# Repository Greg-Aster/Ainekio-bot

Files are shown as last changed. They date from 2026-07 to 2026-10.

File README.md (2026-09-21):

# Ainekio the Robot Familiar

  Ainekio the Robot Familiar is a hardware and software project for building a small robot companion powered by MetaHuman OS. The robot uses a physical body,
  onboard sensors, and a network connection to let MetaHuman OS see, listen, speak, move, and interact through a physical chassis.

- Progress blog and current status: [ainek.io](https://ainek.io)
- MetaHuman OS development repo: [Greg-Aster/metahuman-os](https://github.com/Greg-Aster/metahuman-os)
- Current test body: based on the Sesame robot: [dorianborian/sesame-robot](https://github.com/dorianborian/sesame-robot)

## Robot Models

- **V1 / eight servos:** the existing Freenove ESP32-S3 robot, with direct
  MCPWM servo outputs. [Wiring and hardware records](docs/v1-8servo/PINOUT_DIAGNOSTICS.md).
- **V2 / twelve servos:** native ESP32-P4-WIFI6 bring-up with a PCA9685 driver;
  electrical acceptance and body motion remain pending. [V2 status](docs/v2-12servo/README.md).

Both models are intended to use the same gateway and Body Control interface.
V1 remains supported alongside V2. The complete motion runtime currently implements V1;
[Robot Models](docs/ROBOT_MODELS.md) records the separation boundaries and the
remaining code work for V2.

## Repository Layout

- `Master/` - remote brain and gateway code.
- `Slave/hardware/v1-8servo/` - V1 CAD and physical-body assets.
- `Slave/hardware/v2-12servo/` - V2 CAD, source assemblies, and printable parts.
- `Slave/software/` - portable slave-brain core, protocol, and tests.
- `Slave/firmware/esp32s3/` - current V1 firmware that runs on the robot.
- `Slave/firmware/esp32p4-wifi6/` - native V2 board/network/output-disable bring-up.
- `Emulator/` - host body emulator, Sesame visual simulator, and tests.
- `docs/` - specifications, progress records, repository map, and the ignored
  Sesame reference clone.

The V1 physical robot entry point is
`Slave/firmware/esp32s3/main/app_main.c`. See `docs/REPOSITORY_MAP.md` for the
complete ownership map.

Run the complete local software stack with:

```sh
cp .env.example .env
# Set AINEKIO_ENVIRONMENT_ADAPTER_TOKEN to the adapter token used by MetaHuman OS.
./start.sh
```

This one command starts the visual simulator, protocol-v1 body emulator, Master
gateway, operator dashboard, and authenticated environment adapter. The
launcher refuses to start when the shared bridge token is missing instead of
silently running a disconnected gateway. It prints the dashboard password and
local inspection URLs; pressing `Ctrl+C` stops the entire stack. Run all A1-A30
software acceptance gates with
`python3 Emulator/tools/run_acceptance.py`.

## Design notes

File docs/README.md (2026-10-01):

# Ainekio Documentation Authority

## Normative set

The normative system set is:

- `Ainekio - System Specification v1.0.docx` - behavior, protocol, software,
  safety, and acceptance authority.
- [Parts Overview](https://docs.google.com/document/d/1wz0kyqttPK3HHL0P0_9lLtRW_B87U5u4kEt-UhttHFA/edit?usp=sharing)
  - externally maintained electrical-parts authority named by the specification.

System Specification v1.0 supersedes the archived v0.6 specification and its
Amendment 1 freeze. The Parts Overview supplies planned electrical facts, but
delivered markings, wiring, measurements, photographs, and H-series results are
required before those values count as installed-hardware evidence.

## Maintained implementation documents

Model-specific hardware records live under `v1-8servo/` and `v2-12servo/`.
Shared system, protocol, and bridge documents remain here. The existing
specification's V1 electrical assumptions do not define the V2 board or wiring;
[Robot Models](ROBOT_MODELS.md) records the approved separation and current
implementation boundary.

| Document | Current purpose |
| --- | --- |
| [ROBOT_MODELS.md](ROBOT_MODELS.md) | V1/V2 model, board, servo-output, and shared-code boundaries |
| [V1 hardware bring-up](v1-8servo/HARDWARE_BRINGUP_CHECKLIST.md) | V1 power topology, staged assembly procedure, open physical gates, and recorded board evidence |
| [V1 pinout diagnostics](v1-8servo/PINOUT_DIAGNOSTICS.md) | V1 Freenove header numbering, the flashed GPIO map, peripheral wiring, and expected diagnostic values |
| [V2 hardware record](v2-12servo/README.md) | Selected ESP32-P4-WIFI6/PCA9685 hardware, design assets, and current implementation limits |
| [V2 firmware design](v2-12servo/FIRMWARE_DESIGN.md) | V1 review, P4/PCA9685 requirements, controller/Q6A boundaries and staged acceptance |
| [Body Control Integration](BODY_CONTROL_INTEGRATION.md) | Selected wireless/offboard Q6A direction, USB comparison, ROS 2 role, operating targets and audit findings |
| [Distributed robot foundation](DISTRIBUTED_ROBOT_FOUNDATION.md) | Universal P4 control, Q6A/remote/manual takeover, shared status/routing/queues, ROS comparison and migration gates before feature coding |
| [Complete robot resource budget](v2-12servo/RESOURCE_BUDGET.md) | Power branches, P4/Q6A memory and processing, all equipment, camera/audio quality, motion timing, pins and wired/Wi-Fi comparisons; reproducible arithmetic and final qualification boundaries |
| [Budget audit evidence](v2-12servo/BUDGET_AUDIT_EVIDENCE.md) | Repository/source identities, manufacturer references, Q6A Wi-Fi capability readback, offline Kokoro timing/RSS and exclusions of stale evidence |
| [V2 Step 1 evidence](v2-12servo/STEP1_EVIDENCE.md) | Build/flash commands, tests, actual board/network results and outstanding electrical proof |
| [SLAVE_BRAIN_PROGRESS.md](SLAVE_BRAIN_PROGRESS.md) | Current robot-body software status, implementation evidence, and deliberately pending work |
| [LOCAL_WAKE_WORD.md](LOCAL_WAKE_WORD.md) | Owner-local microWakeWord training, packaging, installation, and validation workflow |
| [freestyle-movement.md](freestyle-movement.md) | Owner-approved bounded motion-plan extension, emulator evidence, and physical enablement gate |
| [REPOSITORY_MAP.md](REPOSITORY_MAP.md) | Current Master, Slave, Emulator, documentation, and reference ownership map |
| [ROS2_SETUP.md](ROS2_SETUP.md) | Desktop ROS tools, validation, and portability requirements for later Q6A deployment |

These documents describe current implementation and evidence. They do not
silently amend the normative specification. A behavioral conflict requires a
numbered specification erratum or revision; installed electrical facts require
recorded H-series evidence.

## Current v1.0 deltas awaiting specification consolidation

System Specification v1.0 predates several implementation discoveries and
owner-approved extensions. Until they are consolidated by numbered erratum or a
new specification revision, readers must keep these boundaries explicit:

- The delivered N16R8 board cannot use the provisional GPIO33/34 servo map in
  specification section 6.3. Hardware testing proved those pins corrupt octal
  PSRAM. The flashed board profile uses GPIO47/48 for R4/R3 and hands GPIO0/43
  from BOOT/UART to the OLED. `v1-8servo/PINOUT_DIAGNOSTICS.md` is the V1 physical
  wiring reference; the old provisional map must not be wired.
- Owner policy as of 2026-08-03 makes the GPIO3 battery sensor telemetry and
  warning-only. The firmware still classifies low, critical, recovered, and
  disconnected readings, but those readings never lock motion, cancel audio,
  close the gateway, or enter deep sleep. Undervoltage shutdown is owned only
  by the battery pack's hardware protection circuit. The installed pack's
  cutoff behavior is not yet documented, so it must be treated as unverified
  and replaced with a properly protected pack if necessary.
- The checked firmware uses a stable per-device eight-character WPA2 setup key
  instead of generating a new 12-character secret for every entry. Joining
  `Ainekio-Setup` is the only setup authentication step; the portal opens its
  configuration form directly at `http://192.168.4.1/` and rejects requests
  outside the setup AP interface. The OLED reports the setup address/key and
  then the joined SSID, DHCP address, and gateway state. This owner-approved UX and
  security change is flashed and broadcasting its setup AP, but still awaits
  physical form-submission evidence and numbered specification consolidation.
- The local wake-word control plane and inference engine are implemented, but no
  accepted production `Ainekio` model is installed. First boot remains
  `wake_enabled=false` and `wake_ready=false`.
- `motion_plan_v1` is an owner-approved bounded extension implemented in the
  protocol/core, gateway, environment adapter, emulator, and current ESP32-S3
  source. The physical port reuses the existing prepared motion buffer/task and
  post-action camera callback. The matching revision is flashed, digest-verified,
  and connected; physical freestyle remains pending owner-supervised transition,
  stop, completion-image, and memory-headroom validation.
- Local robot transport now defaults to `_ainekio._tcp.local` DNS-SD discovery,
  rejects off-subnet advertised addresses, and caches the last authenticated
  local endpoint as a first-attempt optimization. A stale cached endpoint gets
  one bounded attempt before DNS-SD resumes; it is not a fixed configuration.
  Reconnect backoff resets after authenticated `welcome` and never exceeds 15
  seconds. Local mode never silently falls back to the optional Cloudflare
  relay. The owner selected authenticated `ws://` on the private home WPA2 LAN
  as the intentionally minimal local transport; pinned local WSS is not a
  parallel pending path. The maintained implementation uses one-second control
  pings and a four-second active-motion stale guard without timer-driven session
  teardown. Actual Wi-Fi/WebSocket errors still enter FAILSAFE/offline. The v1.0
  DOCX needs a numbered erratum for this
  local-discovery and liveness contract. The keepalive-free application is
  prepared in source but has not yet been flashed; the dated bridge-liveness
  handoff records the exact source-versus-controller boundary.

## Reference inputs

- `Freenove_ESP32_S3_WROOM_Board-main/` contains the vendor board pinout,
  tutorial, driver, and datasheet bundle used to identify physical headers and
  fixed onboard buses. It is reference material, not Ainekio behavior authority.
- `sesame-robot/` is the upstream Sesame source reference used by deterministic
  asset conversion and parity inspection. It is not linked into the runtime and
  does not own Ainekio protocol or safety behavior.

## Archive

`archive/` contains superseded specifications and historical progress material.
Archived files preserve lineage and evidence only; they must not be cited as the
current design. See [archive/README.md](archive/README.md).

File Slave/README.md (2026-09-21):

# Slave

This folder contains the physical robot body and all code that belongs to it.

- `hardware/v1-8servo/` contains the existing eight-servo body's CAD and parts.
- `hardware/v2-12servo/` contains the twelve-servo body's design assets.
- `software/` contains portable robot logic, safety, protocol, and host tests.
- `firmware/esp32s3/` contains the current V1 platform firmware.
- `firmware/esp32p4-wifi6/` contains the native V2 bring-up target and PCA9685 driver.

The ESP32-S3 firmware entry point is
`firmware/esp32s3/main/app_main.c`. The portable control and safety core is
`software/core/` and is compiled into that firmware. Portable WiFi provisioning
state and the versioned NVS contract also live in `software/core/`.

The portable core and protocol currently include V1's eight-joint assumptions.
The approved [model separation](../docs/ROBOT_MODELS.md) keeps reusable control
logic here and assigns each body's joints, poses, and motions to its own model.
V2 command admission and board/network bring-up are implemented. Model extraction,
twelve-joint motion and hardware acceptance remain pending; see the
[Step 1 evidence](../docs/v2-12servo/STEP1_EVIDENCE.md).

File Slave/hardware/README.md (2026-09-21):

# Robot Hardware Assets

| Robot model | Assets | Hardware documentation |
| --- | --- | --- |
| V1 / eight servos | [v1-8servo/](v1-8servo/) contains the existing `3d-print/` and `Parts/` trees | [V1 wiring](../../docs/v1-8servo/PINOUT_DIAGNOSTICS.md) |
| V2 / twelve servos | [v2-12servo/](v2-12servo/) contains V2 source assemblies, Blender files, and printable parts | [V2 hardware record](../../docs/v2-12servo/README.md) |

Source assemblies, Blender work files and backups, and printable exports retain
their original names and contents. A WIP or review filename is not a declaration
of print readiness or physical validation.

Use these model directories for all opens, saves, and exports.

See [Robot Models](../../docs/ROBOT_MODELS.md) for code and board ownership.

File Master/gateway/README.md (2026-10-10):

# Ainekio Gateway

The gateway owns the brain side of each protocol-v1 robot WebSocket. Production
mode authenticates robot sessions, assigns epochs and command sequences, tracks
command lifecycle results, and serves the password-protected local operations
dashboard. Robot tokens, the dashboard password verifier, and the bounded audit
log live under the ignored `build/gateway/` runtime directory by default.

## Physical Robot Gateway

The physical robot and the Environment Bridge share one authenticated,
full-duplex gateway process. Ainekio connects to the LAN-facing `/robot` route;
MetaHuman OS connects from loopback to `/environment`. Non-loopback peers are
rejected from `/environment`, as are requests carrying Cloudflare relay
headers. Once established, either side can send data,
so the fact that the ESP32 initiates its connection does not make communication
one-way.

On first pairing, supply a strong robot token. Configure a separate Environment
Bridge token when using MetaHuman on this host; standalone Body Control does not
require MetaHuman. Do not commit either value:

```sh
export AINEKIO_ROBOT_ID='ainekio-01'
export AINEKIO_ROBOT_TOKEN='<strong generated robot token>'
export AINEKIO_ENVIRONMENT_ADAPTER_TOKEN='<strong generated environment token>'
# Optional first-run password; later launches reuse the saved password.
export AINEKIO_DASHBOARD_PASSWORD='<strong local dashboard password>'
./Master/start-physical-gateway.sh
```

The launcher listens for the robot and Environment Bridge on `0.0.0.0:8790`
but permits `/environment` only from loopback and keeps the dashboard on
`127.0.0.1:8791`. In the default local mode the
launcher advertises `_ainekio._tcp.local` with a host-specific service name. P4
firmware advertising `gateway_switching_v1` tries the saved addresses for its
associated Wi-Fi, then discovered protocol-v1 LAN gateways on that subnet. It
keeps an authenticated connection until that connection fails or the gateway
stops. Discoveries are bounded to eight and stay in RAM for that network
association. A
same-computer MetaHuman OS process continues to use
`ws://127.0.0.1:8790/environment`. Runtime tokens and password verifiers remain
under ignored `build/gateway/physical/` storage.

Older P4 firmware retries one configured URL and requires an update for this
switching behavior. The S3 consumer retains its single-candidate ambiguity result.
The [distributed foundation](../../docs/DISTRIBUTED_ROBOT_FOUNDATION.md) records
the remaining cross-installation work and control-grant design.

This one-off home deployment intentionally uses authenticated `ws://` on the
owner's private WPA2 LAN. It is the smallest local path, but the LAN is part of
the trust boundary: do not use it on guest, shared, or public WiFi. Remote
endpoints remain explicitly configured `wss://` addresses with certificate
verification. TLS-only Wi-Fi profiles never fall back to discovered plain WS;
configure a LAN address on that same network to opt into discovery there.
The dashboard reuses its saved operator password across launches. A first run
without `AINEKIO_DASHBOARD_PASSWORD` generates and prints a password once when
launched in an interactive terminal; an unattended first run requires that
environment variable. Later launches do not generate or print another password.
Use **Settings → Body Control password** to change it with your current password.
The environment variable seeds a missing password store only; it cannot undo a
later password change. Only the verifier persists; plaintext passwords are not
saved by the dashboard. Browser sessions last 30 days and survive server
restarts. Logging out revokes the session. A password change keeps the current
browser signed in and signs out other browsers.
Session token hashes and CSRF state are stored in the owner-only ignored runtime
file `dashboard-sessions.json` alongside `dashboard-auth.json`.
Dashboard authentication is separate from robot WiFi setup and is never
presented by the ESP32 setup portal.

**Settings → Robot Wi-Fi and pairing** reads and edits P4 settings over the
existing authenticated connection when firmware advertises `robot_settings_v1`.
Older firmware shows an update message. The operator can save four connection slots,
each with Wi-Fi credentials and a Body Control URL, remove a connection,
change the robot setup-hotspot password, and change its pairing token. Passwords
are write-only: unchecked password options preserve the saved secret; checking
an option with an empty Wi-Fi password explicitly selects an open network.
WPA2 passphrases follow the radio's 8–63 ASCII requirement (station profiles also
accept a 64-digit hexadecimal PSK); the dashboard login has no such policy.
With `gateway_switching_v1`, two slots may name the same Wi-Fi and different
computer/tunnel addresses. They share one Wi-Fi password; changing it updates
all slots for that network. Adding another address may omit the already saved
password. Duplicate network/address pairs are rejected. Older firmware is
explicitly rejected before a same-network alternate is written.

Read the robot settings before editing. Saves carry the device revision so a
stale browser cannot overwrite another editor's changes. Saving disables output
and persists settings without dropping the running connection. **Restart robot
to apply** is a separate confirmed action; normal startup can move servos to
saved Home positions. A save/restart response confirms that operation, not
successful reconnection. Secrets are omitted from readback, status and audit.

Pairing changes persist the old and new credentials on this server before the
robot receives the write. Both survive a gateway restart or ambiguous device
result. The first authenticated connection using the new token promotes it and
retires the old one. Reuse that pending token when retrying an uncertain save;
apply/reconnect before starting another rotation. Other server installations
must be given the matching token separately. The existing Generate/Revoke
controls still manage server pairing only. Startup environment tokens seed
missing identities and never overwrite a saved token.

## Using more than one computer

The robot identity belongs to the robot. Each host runs the same gateway and uses
the existing robot token and Body Control password. Transfer those credentials
once using the existing security owners; copying `.env` alone is insufficient.
On the working computer, from the repository root:

```sh
./Master/start-physical-gateway.sh --export-pairing /tmp/ainekio-pairing.json
```

Privately transfer that owner-only file to the other computer, then run:

```sh
chmod 600 /tmp/ainekio-pairing.json
./Master/start-physical-gateway.sh --import-pairing /tmp/ainekio-pairing.json
./Master/start-physical-gateway.sh --check
```

Import starts no listeners or services and is idempotent for the same credentials.
It validates both stores before writing; different existing credentials are
preserved with an explicit error. A disk failure can leave one newly imported
store; repeating that same import completes it. The bundle contains tokens and
the password verifier, including any pending token transition. It excludes
browser sessions, tasks, action receipts, logs, Python paths, MetaHuman credentials
and Cloudflare tunnel credentials. Delete the transfer file when finished.
Later password/token changes are local to each installation; copy the matching
credentials to other hosts again rather than assuming automatic synchronization.

Both hosts install their own gateway dependencies and use their own checkout's
`.venv`. Keep machine paths out of shared configuration. Each optional MetaHuman
Bridge retains its matching adapter token. The robot relay hostname remains
`/robot` only. A separate Cloudflare Access TCP hostname can connect a remote
MetaHuman desktop as described below; its credentials/configuration stay local.

- **Same LAN:** a paired gateway with local discovery enabled can be found after
  the current gateway stops. Multiple advertisements are candidates, not an
  error or permission for simultaneous controllers.
- **Different hotspots:** save their SSIDs/passwords and server addresses once.
  P4 cycles distinct networks when Wi-Fi is offline, then selects gateways on
  the associated network. Turn off the previous hotspot when switching SSIDs;
  a still-working Wi-Fi connection is retained. With `AINEKIO_HOTSPOT=1`, the
gateway stops its managed hotspot on shutdown.
- **Cloudflare/remote:** save the `wss://.../robot` endpoint on the relevant Wi-Fi.
  It uses the same pairing and command/result contract with verified TLS.

Start Body Control on the desired host and stop it on the current host using
`./Master/stop-physical-gateway.sh` (or Ctrl+C for a foreground launcher).
A returning host does not seize a healthy connection. The P4 destroys the old
WebSocket and closes admission before opening another. Stop/disconnect output
disable and generation fencing remain; interrupted actions return their existing
disconnect outcome. Connection switching does not transfer a MetaHuman objective,
replay movement or copy a durable execution database.

A phone browser can use an available host's password-protected dashboard when
that host's `AINEKIO_DASHBOARD_HOST` is bound to its private LAN address. The
default dashboard remains loopback. Direct on-P4 browser control is separate
from its setup portal and is not implemented by this change.

The launcher stays in the foreground. Press Ctrl+C to stop it. For normal
owner operation it can instead be supervised by the included user service.
The launcher uses `.venv/bin/python3` from this checkout; `AINEKIO_PYTHON` can
select another absolute interpreter path with the gateway dependencies installed.
Check local prerequisites without opening listeners or printing credentials:

```sh
./Master/start-physical-gateway.sh --check
```

This checks the interpreter, dependencies, discovery executable when enabled, and
saved pairing/password-store validity and recognition/Bridge configuration.
It does not verify network/port
availability or a physical connection.

Install the user service for this checkout without enabling or starting it:

```sh
./Master/start-physical-gateway.sh --install-service
systemctl --user daemon-reload
```

The installer preserves unmanaged existing units. After `.env` contains the
required tokens and the check passes, explicitly enable operation with:

```sh
systemctl --user enable --now ainekio-gateway.service
```

After that, the gateway and its discovery advertisement start when the owner
logs in and restart after a process failure. Rerun the installer and daemon reload
after moving the checkout. The unmodified tracked template assumes `~/Ainekio`.

On a host with the Ainekio hotspot services installed, set `AINEKIO_HOTSPOT=1`
in the ignored `.env` to select hotspot mode at startup. In Body Control,
**Settings → Robot connection mode** switches between the existing Wi-Fi network
and the configured robot hotspot immediately, saving the choice in `.env`.
The running gateway starts `ainekio-hotspot-dhcp.service` and its dependencies,
then stops `ainekio-hotspot-interface.service` and its dependent services when
switched to Wi-Fi or when the gateway exits, including a failed startup.
Switching does not restart Body Control. A robot using the hotspot reconnects
through its saved Wi-Fi profiles when that hotspot is turned off.
The operator needs permission to
start/stop those specific system units without an interactive prompt. Disable
their independent boot enablement when using this gateway-owned lifecycle.
The default is `0`, so other hosts need no hotspot services. Body Control's
dashboard login and robot pairing authentication continue to use their existing
owners. The launcher loads `.env`; a direct `python3 -m gateway.server` invocation
uses `AINEKIO_HOTSPOT` from its process environment and saves UI choices to `.env`
in its working directory.

To install these missing services on Ubuntu, install the packaged dependencies
and run the existing-contract installer once as root:

```sh
sudo apt-get install --no-install-recommends hostapd dnsmasq-base iw iproute2 network-manager polkitd
sudo python3 Master/install-robot-hotspot.py --interface wlan0 --operator "$USER" \
  --credentials /private/path/hostapd.conf
```

Run from the repository root; select the actual station interface and an
owner-only (0600) hostapd file containing the existing `ssid` and either
`wpa_passphrase` or `wpa_psk`. Privately copy that identity from the working
host to reuse the robot's saved Wi-Fi credentials. The installer copies only
those fields; desktop interface names and other hostapd settings are not imported.
It preserves unmanaged existing files with an explicit error and installs
no independently boot-enabled hotspot. Stop the gateway before updating the
installed configuration. Set `AINEKIO_HOTSPOT=1` in `.env` and use the normal
launcher to start it.

The radio must support an AP alongside its station connection; inspect `iw list`
for valid interface combinations. The installer adds `aineap0`, leaves the
station connection intact and defaults to 2.4 GHz channel 1. Use `--channel`
for another permitted channel (1–11); hardware limited to one channel requires
a compatible uplink channel or another adapter. Verify actual radio operation.
The separate interface serves the private `10.42.77.0/24` robot LAN, with the
gateway at `ws://10.42.77.1:8790/robot`. DHCP is confined to that interface and
does not advertise Internet routing or DNS. This is the robot-to-gateway link;
the Q6A gateway and configured remote services use the Q6A's existing uplink.
The installer does not configure NAT, remote MetaHuman execution or Cloudflare.
Operator permissions allow only starting/stopping the three named hotspot
units. Stopping the gateway removes its AP and DHCP/hostapd services together.

Updated P4 firmware tries distinct saved Wi-Fi networks in order, allowing 15
seconds per network while offline. It keeps a working Wi-Fi connection; gateway
failure selects other computers on that same network without Wi-Fi roaming.
An unauthenticated gateway attempt expires after 10 seconds, with a 1-second
retry delay and a bounded 2.5-second discovery query after configured candidates.
These are source limits, not measured physical handoff latency. Each slot supplies its own server
URL (for example `ws://10.42.77.1:8790/robot` on the computer hotspot). This uses
normal Wi-Fi association, not Wi-Fi Direct. If no saved network works, the
existing timed setup AP becomes available after 60 seconds; with no networks it
opens immediately. Wi-Fi/controller loss retains the existing output disable
and stale-command fencing, and reconnecting never replays movement.

The AP-only setup page at `http://192.168.4.1/` remains the recovery path. For an
already configured P4, it can replace a network and optionally change its server
address or token; blank address/token inputs preserve those values. Portal
saves restart immediately, as before. The serial configuration path also remains.
Existing single-network NVS configuration and setup passwords are retained when
upgrading; the first save creates the new P4 settings record. No NVS erase is
needed. Board-level switching and provisioning still require device testing.

The physical dashboard uses the selected robot's authenticated JPEG stream as
its first panel; enable the camera in **Camera and audio** if the panel is
waiting for frames. The emulator stack keeps the visual robot simulator in that
position instead. For bring-up testing, the body microphone starts enabled with
the VAD gate; the same panel can turn it off or select another supported gate
and shows the live input level. Camera streaming is local to this dashboard and
is not forwarded as a continuous image stream to MetaHuman.

The robot controller now originates one fresh still after completed physical
actions and VAD-delimited microphone utterances. The gateway receives the
firmware correlation metadata and JPEG, validates them, and forwards one
correlated Environment observation; it does not send a second automatic
snapshot command. MetaHuman can still request `captureImage` directly. These
bounded snapshots share the camera service with the dashboard but are the only
camera images admitted to the Environment observation path.

Bodies advertising `camera_profiles_v1` expose separate **Stream resolution**
and **Snapshot resolution** controls in the existing panel. Stream output is
QVGA or VGA at the selected frame rate; snapshots can also use XGA (1024×768).
The still profile defaults to VGA and stays unchanged when a gateway caller
omits `snapshot_resolution`. Both profiles are runtime settings. One P4 camera
task and JPEG encoder serve both outputs, with no additional image-buffer
allocation. Disabling preview leaves requested snapshots available. A still
has explicit request/action/audio correlation, independent of preview FPS.

This supports a local P4→Q6A preview and occasional remote LLM stills through
the existing gateway and Environment Bridge. Continuous video is not sent to
the remote LLM. Selecting a frame from a low-resolution preview would limit
remote image detail to that preview resolution; requesting a separate encoded
still preserves the option of more detail from the same sensor capture mode.

Run the production gateway with development credentials supplied through the
environment on first startup:

```sh
export AINEKIO_ROBOT_ID='ainekio-emulator-01'
export AINEKIO_ROBOT_TOKEN='local-development-token'
export AINEKIO_DASHBOARD_PASSWORD='local-operator-password'
PYTHONPATH=Master:Slave/software python3 -m gateway.server
```

The dashboard is then available at `http://127.0.0.1:8791/`. If its password
store does not exist, an interactive launch can generate and print a random
one-time password instead of using `AINEKIO_DASHBOARD_PASSWORD`.

The scripted gateway stub remains available for focused body-client tests:

```sh
export AINEKIO_ROBOT_TOKEN='local-development-token'
PYTHONPATH=Master:Slave/software \
  python3 -m gateway.server --stub --commands stand,walk,neutral
```

To expose the generic environment adapter, configure a dedicated adapter token:

```sh
export AINEKIO_ENVIRONMENT_ADAPTER_TOKEN='shared-environment-adapter-token'
PYTHONPATH=Master:Slave/software python3 -m gateway.server
```

The endpoint is `ws://127.0.0.1:8790/environment`. The connecting environment
agent authenticates in its first protocol message. Ainekio does not contain a
MetaHuman URL or call MetaHuman APIs directly.

Completed microphone utterances and completed physical actions arrive with one
firmware-originated correlated still when the camera is ready. Future typed
safety or sensor events should opt into the same controller-owned trigger and
correlation fields. Routine status, heartbeat, individual PCM frames, and
dashboard preview traffic do not produce Environment snapshots.

## Desktop MetaHuman connected to a Q6A through Cloudflare

Run MetaHuman OS and its Environment Bridge on the desktop. Run only the Ainekio
gateway and its Cloudflare connector on the Ubuntu Q6A. The robot connects to
the Q6A gateway's `/robot` endpoint over its local Wi-Fi. No phone is involved.

The existing `Master/start-physical-relay.sh` can add a separate TCP hostname to
its named tunnel. TCP forwarding preserves the inner WebSocket request and the
Q6A connector opens a loopback connection, so `/environment` retains its existing
loopback and adapter-token checks. An HTTP tunnel to `/environment` is rejected
because it adds Cloudflare relay headers. TCP forwards the gateway port, including
both `/robot` and `/environment`; it is not a path-filtered HTTP route. The
dashboard remains on its separate, unrouted port.

### Q6A setup

On Ubuntu, install `python3-venv` and `avahi-utils` for the existing launcher,
then create this checkout's Python environment:

```sh
python3 -m venv .venv
.venv/bin/python3 -m pip install -r Emulator/requirements-host.txt
```

Install `cloudflared` using Cloudflare's
[download instructions](https://developers.cloudflare.com/tunnel/downloads/).
Import the existing robot pairing/password as described under **Using more than
one computer**. Runtime stores and `.env` do not arrive through Git sync.

Use a locally managed named tunnel with the existing relay launcher. If creating
one for the Q6A, run:

```sh
cloudflared tunnel login
cloudflared tunnel create ainekio-q6a
cloudflared tunnel route dns ainekio-q6a bridge.ainek.io
```

Use `bridge.ainek.io` on your Cloudflare-managed domain. Login opens a
browser, or prints a URL you can open on the desktop. In Cloudflare Zero Trust,
create a self-hosted Access application for this exact hostname and an Allow
policy for your login identity before starting the connector. Dashboard login
alone is not the application's Access login.

Set these in the Q6A's ignored `.env`, using the UUID/credentials file generated
on this host and the same adapter secret configured on the MetaHuman desktop:

```dotenv
AINEKIO_CLOUDFLARE_TUNNEL_ID=<tunnel UUID>
AINEKIO_CLOUDFLARE_CREDENTIALS_FILE=/home/<user>/.cloudflared/<tunnel UUID>.json
AINEKIO_CLOUDFLARE_ENVIRONMENT_HOSTNAME=bridge.ainek.io
AINEKIO_ENVIRONMENT_ADAPTER_TOKEN=<shared adapter secret>
```

Keep tunnel credentials outside the checkout. `AINEKIO_GATEWAY_PORT` selects the
gateway origin port when changed from 8790. The legacy robot HTTP hostname is
still configured, but only the separate TCP hostname needs a DNS route for this
desktop-to-Q6A setup. Do not run the same tunnel's connector simultaneously on
another host: Cloudflare can send connections to either installation.

Start the gateway and connector in separate terminals for the first test:

```sh
./Master/start-physical-gateway.sh --check
./Master/start-physical-gateway.sh
# In a second terminal:
./Master/start-physical-relay.sh --check
./Master/start-physical-relay.sh
```

`--check` validates the local relay configuration; it does not prove the Access
policy, DNS, Internet connectivity, or a robot connection. Keep both processes
running. The gateway's existing user service is documented above. For unattended
connector startup after reboot, use Cloudflare's documented
[Linux service setup](https://developers.cloudflare.com/cloudflare-one/networks/connectors/cloudflare-tunnel/do-more-with-tunnels/local-management/as-a-service/linux/)
with the generated `build/gateway/cloudflare/ainekio-robot.yml` config. Regenerate
it with the relay's `--check` after changing `.env`, then restart that service;
use either the service or the foreground relay launcher to own the connector.

### Desktop setup and test

Install `cloudflared` on the desktop, then in the MetaHuman checkout run:

```sh
./bin/connect-environment bridge.ainek.io
```

This opens local port 18790. Configure MetaHuman's ignored `.env` with
`MH_ENVIRONMENT_ADAPTER_URL=ws://127.0.0.1:18790/environment` and
`MH_ENVIRONMENT_ADAPTER_TOKEN` matching the Q6A's adapter secret.
`MH_ENVIRONMENT_BRIDGE_TOKEN` remains the desktop's existing internal service
token; it is separate from the adapter secret. Restart MetaHuman to load changed
environment variables. Alternatively set **Agent Monitor → Environment Bridge
→ Adapter URL** when `MH_ENVIRONMENT_ADAPTER_URL` is absent; the environment
variable takes precedence over that setting.

When the Bridge connects, the desktop connector opens a browser for Cloudflare
Access authentication. A desktop shortcut can run the forwarding command.
Keep the forwarder running, and use Agent Monitor's existing Bridge state and
diagnostics to verify the returned gateway session and connected robot. Test an
owner-selected command and its returned receipt, followed by the intended camera,
microphone and speech paths, before calling the demo ready. No motion is started
by the tunnel or desktop forwarding launchers.

This transport uses Cloudflare's
[Access TCP workflow](https://developers.cloudflare.com/cloudflare-one/access-controls/applications/non-http/cloudflared-authentication/arbitrary-tcp/).
Cloudflare recommends Client-to-Tunnel for
[long-lived connections](https://developers.cloudflare.com/cloudflare-one/networks/connectors/cloudflare-tunnel/routing-to-tunnel/protocols/).
The local TCP-forwarding regression test establishes gateway compatibility, not
Cloudflare authentication, Q6A performance, Wi-Fi latency, or physical behavior.

## Updating an ongoing movement

The authenticated Environment adapter accepts `environment.action.update` for
an already-admitted, ongoing V2 walk. It updates the original command through
the same gateway and body lease; it does not submit another cognitive action or
take task ownership from MetaHuman. The original action must have passed the
existing accepted-feedback admission gate before updates can be sent.

The `bridge.ready` observation exposes `state.activeMovementUpdates`. Updates
are available only for an online, motion-ready V2 body advertising ongoing
locomotion and command deadlines. Composed steering additionally requires
`walk_steering_v1`; use only the advertised `controls`. Older supported bodies
keep speed/stride/rate updates and explicitly reject steering before dispatch.
Use its `gatewayInstance`, the body's current
`robotId`/`epoch`, the original `actionId`, and the exact original `bodyLease`:

```json
{
  "type": "environment.action.update",
  "version": 1,
  "sessionId": "ainekio-01",
  "gatewayInstance": "<current gateway instance>",
  "robotId": "<connected robot ID>",
  "epoch": 7,
  "actionId": "<original action ID>",
  "bodyLease": {
    "bodyId": "ainekio-01",
    "executionId": "<original execution ID>",
    "generation": 1
  },
  "revision": 1,
  "validForMs": 500,
  "controls": {"speed": 70, "forward": 80, "turn": 25}
}
```

`controls` accepts `speed` **or** both `stride` and `rate`, using the existing
walking protocol ranges. Optional paired `forward` and `turn` percentages
(-100 through 100) compose translation and yaw in the running gait. Positive
forward advances; positive turn turns left. The original direction and gait
identifiers stay attached to the original command; composed steering is
interpolated over a gait cycle without resetting its phase. Finite movements cannot be converted into ongoing
walks. Servo targets and additional control fields are rejected. The body retains
its existing gait interpolation, coordinated timing and calibrated limits.

Use increasing positive integer revisions, up to 2,147,483,647. A revision
reserved for dispatch is stored in the original receipt and cannot be replayed,
including after reopening the receipt store. Send one update at a time and await
its result; a second concurrent update is rejected rather than queued.

`validForMs` is an integer from 1 through 2000, measured from receipt at this
adapter. The gateway's configured action-age limit can shorten it. Expiry,
lease, cancellation and connection identity are checked before dispatch; the
remaining validity also reaches the P4 through its existing command deadline.
Queueing and body receipt do not restart that validity. Upstream observation age
and transport delay before adapter receipt are separate and remain the sender's
responsibility.

The reply is `environment.action.update.result`, with the same `actionId` and
`revision`, a wire `sequence` when assigned, and status `acknowledged`, `rejected`
or `outcome_unknown`. An acknowledgement confirms body acceptance of the update;
it does not complete the parent task or verify measured motion. If the body's
reply times out after dispatch, further updates are blocked until that sequence
has a terminal receipt. Cancellation remains available while awaiting a reply.
Update results are not cognitive feedback and are not replayed to a new bridge.
The original action retains its normal completion/cancellation receipt.

MetaHuman's canonical active task executor now produces these updates through
the existing Coordinator and Bridge. The Bridge correlates each update receipt
to its finite settings job while leaving the original movement active. Task
programs use semantic moves, rather than a new body-level search command. Object-recognition model
comparisons are deferred to the assembled prototype.

Desktop coverage includes an authenticated WebSocket bridge, the real gateway
command path with a simulated body, parent-action lifetime, cancellation and
ownership changes, expiry, replay, reconnect identities and lost receipts:

```sh
PYTHONPATH=Master:Slave/software:Emulator:Emulator/tests \
  python3 -m unittest Emulator.tests.test_active_movement
```

## Continuous camera processing

`gateway.plugins.CameraFramePlugin` processes camera images outside the robot
receive loop. It retains one image being processed and one waiting image; each
new arrival replaces the waiting image. Synchronous consumers run on one worker
thread, and async consumers run in a separate task and must yield during I/O.
Slow inference therefore does not make the receive loop await the model.

An optional `observe` callback receives a `CameraAnalysis` containing the
backend's result, robot ID, connection epoch, frame counter, and monotonic
receipt/completion times. The backend can return detector boxes or a vision LLM
description; the gateway does not reinterpret either as verified identity or
task completion. Consumers must not treat model scores as measured probabilities.

The plugin drops frames/results that exceed `max_frame_age_s` (default one
second), belong to an ended connection epoch, or have a stale control heartbeat.
Set this limit for the intended observation use before selecting a backend.
Receipt time is **not** sensor capture time: it excludes age accumulated before
the gateway received the image. Acquisition timestamps and frame-associated
robot pose remain necessary before using image geometry for motion control.

The owner must await `plugin.aclose()` on removal or shutdown. Closing
unsubscribes the plugin, discards waiting frames/results, and joins its worker.
A running native inference call cannot be killed by coroutine cancellation;
shutdown waits for that call, so inference backends need their own bounded
request deadlines. This thread separation does not establish hard real-time
behavior for CPU-bound Python code or under system-wide load.

At the current 256 KiB JPEG transport cap, the two retained input images use at
most 512 KiB of payload storage. Model weights, decoded images, intermediate
tensors, results, and runtime overhead require a separate measured budget.

## Configured recognition and MetaHuman handoff

The production gateway can connect the camera worker to an explicitly configured
local or remote vision service. It uses the Chat Completions image/JSON interface supported
by services such as [vLLM](https://docs.vllm.ai/en/latest/features/multimodal_inputs/).
The model must support images and JSON output. No model, weights, package or
inference server is installed or started by this gateway.

```sh
export AINEKIO_VISION_URL='https://your-recognition-host/v1/chat/completions'
export AINEKIO_VISION_MODEL='your-served-vision-model'
# Set AINEKIO_VISION_API_KEY in the ignored .env or the service environment.
# Start the existing authenticated production gateway with these settings.
```

Equivalent CLI options are `--vision-url`, `--vision-model`,
`--vision-timeout-s` (default 2), and `--vision-max-frame-age-s` (default 1).
The frame-age limit must be 0.1–30 seconds and includes inference time; choose it
for the consumer's freshness needs. The URL and model must both be configured,
and the authenticated Environment Bridge must be enabled. Omission disables
recognition while leaving preview and correlated stills available.

An optional local detector uses `--vision-yolo-weights /absolute/path/to/existing.pt`
instead of the URL/model pair. `--vision-yolo-device` defaults to `cpu` and
`--vision-yolo-image-size` to 640. It uses the same camera worker, freshness limit,
`RecognitionResult`, authenticated bridge and behavior owner. Ultralytics must
already be installed in the explicitly selected Python environment; the gateway
does not install packages or resolve a model name into downloaded weights. Only
detection/segmentation checkpoints are accepted. Labels come from that checkpoint's
class map, and segmentation supplies boxes, not distance estimates. The model
identity includes the weights SHA256. This option does not enable camera capture.

To retain the local detector across normal launcher restarts, set
`AINEKIO_VISION_YOLO_WEIGHTS`, `AINEKIO_VISION_YOLO_DEVICE` and
`AINEKIO_VISION_YOLO_IMAGE_SIZE` in the existing ignored `.env`. Command-line
options override these values. `AINEKIO_PYTHON` selects the existing interpreter
with Ultralytics installed. Body Control's camera panel reports whether recognition
is configured, observation age, fresh-result rate, received frames and errors.
These ages start at gateway receipt, not camera exposure.

Body Control's **Vision and robot control** section separates three saved choices:
camera settings are stored per robot in the gateway data directory and reapplied
on that robot's next connection; recognition can be switched off without stopping
preview (queued and late inference results are discarded); MetaHuman robot control
uses Core's existing saved Environment Bridge setting over the authenticated bridge.
Switching robot control off cancels the active owner's robot executions through
the Coordinator and keeps unresolved command receipts available for reconciliation.
Switching it on permits new instructions, without restarting cancelled executions
or changing the configured Reactive/Semi/Full mode. Manual controls remain independent.
An off setting or cancellation request does not establish physical rest.

### Named people (optional local models)

The existing camera worker can combine YOLO person boxes with OpenCV YuNet face
detection and SFace embeddings. Explicit local paths select the additional models:
`AINEKIO_VISION_FACE_DETECTOR=/absolute/path/face_detection_yunet_2023mar.onnx`
and `AINEKIO_VISION_FACE_RECOGNIZER=/absolute/path/face_recognition_sface_2021dec.onnx`.
Both are required alongside the existing YOLO configuration. Nothing downloads
automatically, changes the selected detector, starts capture, or issues commands.
OpenCV must provide `FaceDetectorYN` and `FaceRecognizerSF` in the selected Python.
Model sources and licenses: [OpenCV YuNet](https://github.com/opencv/opencv_zoo/tree/main/models/face_detection_yunet)
and [OpenCV SFace](https://github.com/opencv/opencv_zoo/tree/main/models/face_recognition_sface).

In **Vision and robot control → Recognition → Named people**, enter a name and
upload a clear single-face JPEG of at most 256 KiB. Add different views using the
same name, up to four samples per person and 16 people. The authenticated gateway
processes the selected file on its host; it discards the photo and stores names,
stable person IDs and embeddings in owner-only `known-people.json` alongside its
existing private settings. Do not commit or publish that file. **Forget** removes
the enrolled features and invalidates inherited names. Enrollment persists across
restarts, but live track IDs do not. Changing the recognition model requires
explicit re-enrollment, not reinterpretation of old features.

Fresh typed observations retain `label: person` and add an optional `identity`:
`trackId`, and `state` (`unknown`, `face_match`, or `tracked`). Named estimates
carry `personId`, `name`, and `faceAgeMs`; a fresh face match also carries cosine
`similarity`, not a probability. The paired Core perception validator must support
these fields before enabling the face models. The composite observation model
hash binds YOLO, YuNet and SFace; dashboard status exposes the two face model hashes.

Matching uses SFace's reference cosine threshold 0.363 with a 0.08 separation
from the next enrolled person. These are starting parameters, not measured
accuracy on this robot. Tracking accepts mutually unambiguous box overlap and
color continuity, for gaps no longer than 1.5 seconds and up to 3 seconds after a
face match. Fresh unmatched faces, ambiguous crossings and simultaneous duplicate
identity matches lose the name. Missing detections emit no visible track. Reconnect,
recognition off/on, and gallery changes reset continuity; stale or discarded
inference never commits tracking state. Reappearance can be named again by a fresh
face match, with a new track ID.

**Limit:** short box/color association is not robust body re-identification.
Similarly clothed people replacing each other without a visible face can still
produce an incorrect `tracked` estimate. Small/turned/occluded faces, lookalikes,
photos and displays can defeat recognition; there is no liveness verification.
The UI separates these estimates from fresh matches and hides expired results.
This addition does not change behavior selection, automatic stopping, manual
ownership, or the existing single-person loss policy. Named-person following in
crowds is not qualified by these observations or by deterministic tests.

Focused software checks (no body connection, synthetic face embeddings):
```sh
PYTHONPATH=Master:Slave/software:Emulator/tests python3 -B -m unittest \
  Emulator.tests.test_person_identity Emulator.tests.test_camera_perception \
  Emulator.tests.test_gateway_dashboard Emulator.tests.test_yolo_backend
```
Qualification still requires approved model files, actual face inference, enrolled
person recordings including crossings/occlusion/replacement, and measured latency.
Do not interpret synthetic matching/ownership tests as recognition accuracy.

The evaluated desktop checkpoint `person_yolov8m-seg.pt` supports **person only**,
not the general COCO class set or personal identity. Offline evaluation used
Ultralytics 8.4.36, PyTorch 2.11.0+cu130, OpenCV 4.13.0, Python 3.12.3, and an
i9-9900K with four CPU threads (GPU unused). On the packaged public bus image,
ten warm predictions measured median 210 ms, maximum 247 ms and 4.64 serial fps;
peak process RSS was about 1.02 GiB. Cold library import took 68.6 seconds with
observed filesystem waits; first prediction took 496 ms. These are desktop
measurements, not Q6A performance, accuracy qualification or response guarantees.
The recorded-image trial requires a preexisting isolated `YOLO_CONFIG_DIR` and
sets `YOLO_OFFLINE=true`, `YOLO_AUTOINSTALL=false`, and `OMP_NUM_THREADS=4`.

Do not activate this option on a live installation or direct its frames to a
new inference endpoint without operator approval. For the intended split, one
Q6A Core/Coordinator and gateway keep task ownership while an explicitly approved
desktop endpoint supplies inference. The existing remote provider contract is
retained; no second scheduler, takeover or desktop controller is introduced.
`AINEKIO_VISION_API_KEY` supplies a Bearer authorization header; it is required
for a remote service and optional for a loopback service. Remote endpoints must
use HTTPS with normal certificate and hostname verification. Private certificate
authorities can use Python's standard `SSL_CERT_FILE` trust configuration; there
is no TLS-disable option. HTTP is retained only on a loopback IP (or `localhost`,
pinned to 127.0.0.1). URL credentials, queries, fragments and control characters
are rejected. Proxies and redirects are not followed. Images go only to this
operator-configured endpoint; observations cannot supply another destination.
The gateway's one bounded camera worker handles transport and validation while
the remote server performs heavy perception. The existing correlated remote
snapshot path is unchanged; no second runtime or task authority is added.

[`RecognitionResult`](perception.py) contains a bounded summary, up to 32
candidate objects, and up to 8 uncertainties. Object labels may carry optional
scores and normalized top-left `x/y/width/height` boxes. Missing scores or boxes
stay absent. Scores are estimates, not calibrated probabilities; a label does
not verify physical identity, task completion, distance or walkability. A
detector can return the same result type through the existing camera consumer
without changing the bridge or MetaHuman. Backend errors, incomplete JSON and
oversized responses are failures, not empty successful observations. Current-body
failures reach the existing `environment.observation` route as
`metadata.recognitionFailure` with robot/epoch/frame/gateway correlation and an
explicit reason (including HTTP authentication failures and timeouts). They do
not fabricate objects, body completion, or an automatic stop policy.

The adapter emits `environment.telemetry` with `kind: "vision.recognition"`
and a compact `perception` record: version 1, robot ID, connection epoch,
gateway instance, frame counter, backend/model, receipt-based `observedAt` and
`expiresAt`, summary, objects and uncertainties. `timeBasis: "gateway_receipt"`
explicitly excludes unmeasured sensor/transport age. Results expire from frame
receipt, not inference completion. Recognition metadata has no image data and
is not replayed after bridge reconnection.

Recognition telemetry also carries optional `processing` diagnostics outside
the unchanged perception-v1 payload. `CameraFramePlugin.metrics()` reports input,
completed processing attempts, fresh results, drops, stale frames and errors;
queue depth; latest queue/inference durations; age since host receipt of the last
fresh processed result; and processing/fresh-result rates since the first frame.
Failed attempts count as processed but not fresh. Fresh-result counts describe
the camera worker, not confirmed bridge admission; they include the current result.
These counters cover the worker, including all robot streams it subscribes to. Host-receipt age excludes
unknown camera exposure and transport delay, and changes continuously even when
no new frame arrives. No diagnostic count establishes a fresh observation.

The opt-in paired test `perception-gateway.spec.ts` in Core launches
`Emulator.tests.perception_harness`. It reuses the existing in-memory body and
gateway receipt owners, rejects all Python socket connects/binds/listens, and
accepts only explicit local weights and a recorded image. Commands cannot reach
a physical robot through this test path. It exercises real detector output and
Core behavior while instruction and conversation inference are deliberately
pending. The paired Core command `tests/run-visual-control.sh GATEWAY PYTHON
WEIGHTS BUS_JPEG OUTPUT` produces an HTML frame/steering report and correlated
JSON traces. It translates one person cropped from the packaged public photo,
runs actual recognition, includes target loss and expired input, and checks
confirmed cancellation versus a missing original receipt using the production
confirmation budget. Fresh target loss returns to the selected base motion;
expired required feedback requests cancellation. Task selection is scripted,
so this does not qualify unresolved language-model interpretation failures,
natural video accuracy or physical rest. No image is sent to an LLM. See Core's
`docs/technical/visual-control-demo.md` for exact setup and remaining gates.

MetaHuman's existing Environment Bridge coalesces recognition delivery to one
active and one newest pending result, independently of control receipts. Core
validates its contract and robot/session identity, rejects old frames, and stores
it in the existing observation's `state.perception` without replacing its still
image or renewing its control heartbeat. The existing **Environment Bridge
Input** exposes a fresh `perception` output; live observation reads remove
expired recognition while recorded evidence remains intact. Recognition arrivals
create no new objective or independent body job. An existing MetaHuman local
task can resume on recognition through its execution ledger and Work Coordinator.
MetaHuman retains task and movement decisions through the same body leases.

MetaHuman's sole active task executor accepts complete ordered programs from
Environment Mode and the autonomy selector. It advances saved gestures from
physical receipts without additional model calls, and can retain an ongoing gait
while fresh recognition steers it. Target identification uses free-text phase
criteria and finite asynchronous snapshot/model jobs. A confirmed identification
requests Finish on the original gait; its terminal receipt precedes subsequent
gestures, which run before the
whole task is complete. This replaces the temporary repeated-motion local-task
route and the per-movement Action Result model workflow. MetaHuman remains the
commander; processing services do not acquire another motion channel.

Stage 1 stopping policy (source/software only, 2026-10-07): normal Finish is a
speed-zero update, preserving concurrent speech. MetaHuman allows 5 seconds for
the original gait's terminal receipt, then uses owned cancellation. Failed or
expired required feedback requests cancellation promptly. Adapter cancellation
has a 2-second send/confirmation budget and requires the original command's
terminal receipt; a Stop ACK alone cannot terminate older action records.
MetaHuman also bounds its confirmation wait and retains `outcome_unknown` when
transport or receipt confirmation is unavailable. These bounds depend on the
existing Coordinator and transport; they are not a firmware feedback watchdog.

Cancellation and steering validate the immutable action/lease, gateway instance,
robot epoch and latest body dispatch inside the same send lock as manual control.
An unguarded manual update also invalidates autonomous cleanup authority. Speaker
cancellation is separately fenced. Capture cancellation never issues a body-wide
Stop. Disconnect/reconnect evidence stays unknown; old motion is never replayed.
A correlated terminal receipt establishes commanded execution outcome, not sensed
physical rest or measured servo position. Emergency Stop still sends the existing
P4 output-disable command and can interrupt speech.

Stage 2 instruction interpretation (software only) runs as finite Coordinator work
alongside the same MetaHuman execution. The approved pending-turn policy combines
all unanswered messages in order and attributes the response to the newest turn.
An interpretation-origin body command carries `metadata.interpretationBody`
(session, gateway instance, robot, epoch, last body sequence). The adapter checks
that fence under the existing wire-send lock; manual commands and body-session changes
invalidate late proposals. Every body command in an interpreted program keeps
this check. Admitted body dispatches persist `data.interpretationBody` in their
correlated receipt; Core advances its expected ownership from that receipt, never
from a newer live status snapshot. Steering updates keep the original action's
owner, and owned cancellation advances it to the Stop dispatch. Failed admission
cannot mint successor ownership. Stored receipt replay keeps the same evidence
across adapter recovery; a different gateway session or robot epoch invalidates
old commands. Emergency Stop remains independent of interpretation.
Owned cancellation records its Stop dispatch fence in `data.cancellationBody`,
including unknown results, so MetaHuman can distinguish its cleanup from a later
manual takeover. That ownership evidence never substitutes for the original
command's terminal receipt or proves physical rest. No firmware change is needed.

Before deployment, identify the actual MetaHuman/gateway/P4 versions and reconcile
old active executions. Supervised checks must cover normal Finish with speech,
required-feedback expiry, Stop plus original cancellation receipt, missing/late
receipts, manual takeover and reconnect. No firmware or service was changed on a
running robot during Stage 1; IMU and vision setup remain separate work.

Metric navigation, tracking, live IMU feedback and hardware qualification remain
separate work. Model comparisons remain deferred to the assembled prototype.

Desktop replay and WebSocket tests cover newest-frame delivery, stale/session
rejection, processing failures, shutdown, and command/stop receipts while
synchronous inference is blocked:

```sh
PYTHONPATH=Master:Slave/software:Emulator:Emulator/tests \
  python3 -m unittest Emulator.tests.test_recognition_backend \
  Emulator.tests.test_camera_perception \
  Emulator.tests.test_gateway_service Emulator.tests.test_environment_adapter \
  Emulator.tests.test_action_receipts
```

These tests use synthetic observations and the host emulator. They do not
qualify object-recognition accuracy, Q6A throughput, Wi-Fi latency, or physical
movement.

## P4 assembly calibration

Body Control uses the connected body's advertised capabilities. The P4 joint
panel reads twelve saved/staged device records through `body_calibration_v2`;
it does not reuse the eight-servo angle contract. Select the joint, enable
calibration, then use a pulse target or ±5 µs adjustment. **Use commanded pulse
as home** stages the trim; **Save calibration** applies edited joint settings,
commits them and displays the controller's readback. A pulse entered for **Move
joint** is not automatically a Home setting. Saving disables outputs without rebooting; **Home
selected joint** or an explicit move resumes that joint. **Read from body** is
available without enabling calibration. Home and pulse targets use µs, and
the displayed pulse is a command, not a shaft-position sensor reading.

The pulse slider previews a calculated model angle from the controller's Home,
direction and µs/degree mapping, and sends one movement request after release.
Its view includes the owner's observed 300–2900 µs span and expands for Home,
the last commanded pulse or typed targets; this does not change saved calibration. Numeric
entry remains available across the reported PWM capacity.
The selected robot/joint, pulse target and joint-setting drafts are retained in
this browser across reconnects and reloads. **Resume calibration** requests mode
entry explicitly; restoration never replays a movement or saves settings.
Controller readback is shown separately. **Use controller values** discards the
selected joint's local draft without moving it.

Channel -1 disables a joint. Staging Home, direction or channel does not move
outputs. P4 motion uses the model angle at Home, pulse direction and µs per degree
from the same records. The P4 mapping form has no minimum or maximum pulse fields.
Manual and generated motion use the body's actual PWM timer capacity.
The owner sets Home, direction and angle scale from actual positioning behavior.
Named poses
come from the body's installed catalog; walk/crawl exposes direction, continuous
or finite cycles, speed/stride/rate and Finish when `walk_controls_v2` is present.
Calibration mode does not block semantic motion. A pulse outside the PWM timer's
capacity is rejected by the body rather than silently rescaled.
Unsupported or disconnected media controls show the body's reason;
V1 controls retain their existing wire protocol. `/api/calibration/body` requires
the dashboard session and CSRF token; Environment Bridge exposes no raw joint
calibration action. The former `/api/diagnostics/output` bench route is removed.

The P4 SD panel reads controller capacity, mount/busy state and dropped records.
**Retry mount** works with an unmounted card. **Clear logs and captures** requires
an explicit confirmation and controller readback; it does not reformat the card.
Media controls follow current capabilities reported in regular body status, so
a camera that finishes initializing after the handshake becomes available
without reconnecting. Speaker PCM is paced at 20 ms per frame with at most
100 ms of prebuffer/catch-up lead; cached utterances cannot be sent as an
unbounded burst into the controller's playback queue.

### V2 mounting references

Current P4 calibration readback separates saved per-joint mappings from recommended mounting offsets, reports `servo_profile_id` and `profile_confirmed`, and labels shaft travel unmeasured. The observed 300–2900 µs span has arithmetic midpoint 1600 µs; the selected mounting reference is 1300 µs. The panel shows the recommended model offset without overwriting restored drafts or transmitting settings automatically. Review the mapping and Save before semantic motion; after outputs are disabled, establish a known reference with Calibration Home/Move. See the [assembly guide](../../Slave/software/models/v2-12servo/SERVO_ASSEMBLY.md).

### Physical gateway startup connection choice

Running `Master/start-physical-gateway.sh` in a terminal asks how you will open
Body Control: **This computer**, **LAN / Wi-Fi**, or **Cloudflare**. Press 1, 2 or
3 and Enter, or press Enter to keep the saved choice. After 10 seconds without
input, it uses the saved choice automatically. The first start defaults to
**This computer**. Noninteractive/service starts use the saved choice immediately.

The startup choice is stored on the gateway machine in
`build/gateway/physical/dashboard-connection.json` (or under the configured
`AINEKIO_GATEWAY_DATA_DIR`) and survives closing the program and rebooting.

- **This computer** binds the dashboard to loopback and prints its local address.
- **LAN / Wi-Fi** binds the dashboard to `0.0.0.0` and prints a LAN address.
  Existing dashboard login still applies. It uses the computer's current network;
  it does not select an SSID or change the robot's saved Wi-Fi settings.
- **Cloudflare** binds the dashboard to loopback and prints its configured public
  address. The existing tunnel must already be running and route that address
  to the dashboard port. This launcher does not create or manage another tunnel.
  Choosing Local or LAN does not disable an independently running tunnel.

Configuration:

```bash
# Supply your own already-configured dashboard hostname; saved after selection.
AINEKIO_DASHBOARD_PUBLIC_URL=https://body.example.com Master/start-physical-gateway.sh
# Override the saved choice without prompting (also accepts lan or cloudflare).
AINEKIO_DASHBOARD_CONNECTION=local Master/start-physical-gateway.sh
# Optional timeout in seconds; default is 10.
AINEKIO_DASHBOARD_CHOICE_TIMEOUT=5 Master/start-physical-gateway.sh
```

Explicit `AINEKIO_DASHBOARD_HOST` still overrides the selected listen address;
check the printed bind address when using it. Prerequisite checks, pairing
transfer and service installation do not prompt or rewrite the startup choice.
No automatic browser opening or remote gateway startup is performed.

The browser **Settings → Connections** controls remain available. Their saved
addresses belong to each browser and dashboard origin; they do not overwrite
this machine's startup default. Clicking **Save and open** persists those browser
settings, while merely changing the dropdown does not.

### Saved dashboard connections and desktop bridge settings

In Body Control **Settings → Connections**, save dashboard addresses for a local
or forwarded port, LAN/Wi-Fi, and Cloudflare. Each slot can point to any configured
machine; none assumes a Q6A. Opening a destination uses a new tab and its normal
login. Saved addresses belong to this browser and this dashboard origin. On
another device or dashboard origin, configure them there too. These are address
bookmarks, not gateway failover or task migration.

A local address means the device running the browser. A LAN dashboard must be
reachable or already forwarded. A Cloudflare dashboard address needs its own
configured route; the existing `/robot` HTTP relay and Environment Bridge TCP
route do not expose the dashboard. The selector does not change listeners,
install services, create tunnels or select Wi-Fi networks.

Save the stationary desktop's existing MetaHuman web address and use **Open
desktop bridge settings**. This opens `/monitor#body-connection` on that host,
where the MetaHuman owner chooses **This computer**, **LAN / Wi-Fi via SSH**, or
**Remote via Cloudflare**. The desktop's own authentication and bridge lifecycle
remain authoritative; Body Control never receives its credentials. This page
can be reached even while the robot bridge is disconnected. MetaHuman needs the
paired connection-selector source update; older versions open Agent Monitor
without the new selector. Its local option means the MetaHuman host, while its
SSH destination can be any configured machine running Body Control.

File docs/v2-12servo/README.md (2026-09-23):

# V2: Twelve-Servo Robot

V2 is a second Ainekio body developed alongside the existing eight-servo V1.
The owner confirmed the following hardware selection on 2026-09-15.

## Selected Hardware

| Item | Selection and source |
| --- | --- |
| Body | Twelve servos in the new frame; owner-confirmed |
| Controller | ESP32-P4-WIFI6 development board, based on ESP32-P4 with an ESP32-C6 for wireless connectivity; [manufacturer documentation](https://docs.waveshare.com/ESP32-P4-WIFI6) |
| Purchased listing / kit selection | [Amazon B0FLXX1BZ6](https://www.amazon.com/dp/B0FLXX1BZ6), listed with an OV5647 camera and speaker; this records the listing, not installed peripheral evidence |
| Servos | Twelve MG90 servos; owner-confirmed designation. Exact variant and supplier, pulse limits, and measured calibration remain pending. |
| Servo signal driver | HUAREW PCA9685 16-channel PWM breakout, [Amazon B0CRV3MK14](https://www.amazon.com/dp/B0CRV3MK14), supplied by the owner. Used as a standard PCA9685 breakout; the owner confirmed channel-0 servo movement on 2026-09-22. Chip reference: [NXP datasheet](https://www.nxp.com/docs/en/data-sheet/PCA9685.pdf). |

The robot has twelve joints even though the driver provides sixteen channels.
The actual P4 is revision 1.3 with 32 MiB flash and 32 MiB PSRAM. The native target
assigns a dedicated PCA bus to GPIO2/3 and OE to GPIO4. Channel-0 movement is
confirmed; physical joint assignments, horn indexing, travel calibration and
multi-servo power capacity remain to be established. V1 poses and calibration
do not supply those values.

## Wiring Guides

- [P4 pinout image](ESP32P4_Pinout.png)
- [PCA9685 connection image](PCA9685_Wiring.png)
- [Wiring table, sources and servo power](PCA9685_WIRING.md)

The guides match the native firmware's GPIO2/3/4 assignments. Remove power
before adding or moving connectors. See the normal firmware's startup procedure
for connecting servos one at a time.

## Design Assets

[Slave/hardware/v2-12servo/](../../Slave/hardware/v2-12servo/) contains the
existing STEP sources, Blender assemblies and backups, GLB conversions, STL
exports, and source archive. Original filenames and the internal directory
structure are preserved. Use this model directory for all opens, saves, and
exports.

## Software Status

The [firmware review and implementation design](FIRMWARE_DESIGN.md) records the
V1 source findings, P4 platform research, and recommended implementation stages.
It specifies proposed timing/fault contracts and starts with P4/C6/output-disable
hardware checks, followed by supported motion before complete media integration.
It develops the [approved code boundaries](../ROBOT_MODELS.md).
The [native P4 target](../../Slave/firmware/esp32p4-wifi6/README.md) now contains
the PCA9685 driver, automatic startup home, matched C6 networking and shared
command admission. Normal power-on starts channels 0–11 at saved pulses,
200 ms apart; the current source default is the 1300 µs selected assembly reference. The laying pose is
updated in both Blender and the exported rest source: the chassis base
plate and all four lower legs rest on the floor. Midpoint and a calibrated body rest pose are
separate until horn indexing and joint calibration are established. Temporary
bench commands and fault injection have been removed. See the firmware README
for normal operation and the historical [Step 1 evidence](STEP1_EVIDENCE.md) for
earlier measurements and unmeasured electrical behavior.

The optional Q6A deployment, controller-selection boundary and future native USB
reservation are documented in the firmware design. No Q6A services are implemented.
The [V2 model](../../Slave/software/models/v2-12servo/README.md) contains the
variable forward gait with automatic Speed and advanced stride/cadence controls,
plus 29 finite motions regenerated for the same current leg and sole geometry.
The Blender project includes a separate **Motions - Current Geometry** scene
with all 30 motions and a selector for individual commands. The gait is integrated through
`walk_controls_v1`; walking and gesture execution remain disabled. The
[2026-09-17 integration record](MOTION_INTEGRATION_20260917.md) covers all 30 motions,
the successful software checks, and the migration to the larger application partition. Calibrated physical execution,
joint calibration and the V2 simulator remain pending. The shared gateway
negotiates model/readiness and does not advertise unimplemented P4 motion/media.

## Servo range and assembly update

The current servo profile uses the observed 300–2900 µs span, a selected1300µs reference, and geometry-derived mounting offsets. Actual angular travel is still unmeasured. Follow the [twelve-joint assembly guide](../../Slave/software/models/v2-12servo/SERVO_ASSEMBLY.md). Original gait and motion sources are restored unchanged. The separate internal-leg clearance audit flags unresolved conflicts; these need owner review before assembly. Existing deployed firmware evidence below the current design tracker refers to the previous application.

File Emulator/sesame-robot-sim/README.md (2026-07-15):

# Sesame Robot Simulator

This folder contains a local copy of the prebuilt browser simulator from:

- Upstream simulator: https://github.com/one-for-all/sesame-robot-sim
- Upstream commit copied: `5e5299e92e72e579d5deb6746ab61ba316114a03`
- Related robot project: https://github.com/dorianborian/sesame-robot

The runnable app is in `app/`. It is the upstream `docs/` build, copied here so it can be served locally without rebuilding the Rust/WASM/ESP32 toolchain.

## Run

From the repo root:

```bash
./Emulator/sesame-robot-sim/run.sh
```

Then open:

```text
http://127.0.0.1:8765/
```

To use a different port:

```bash
PORT=8766 ./Emulator/sesame-robot-sim/run.sh
```

## Notes

This is not a full source checkout. Rebuilding the simulator from source requires additional sibling dependencies used by upstream, including `gorilla-physics` and `esp32rs`, plus the Rust/WASM and ESP32 firmware toolchains.

The simulator is useful for motion and firmware experiments, but upstream currently describes it as rudimentary: servo simulation and serial monitor are present; OLED and Wi-Fi are not implemented.

The `source/` folder is provenance only. Ainekio loads the exact visual runtime from `app/` inside the local operator dashboard.

The visual renderer is optional for protocol tests. If this page is not open,
the Ainekio host body executes motion headlessly and returns a normal terminal
lifecycle. A headless command is not cached or replayed when the page is opened
later.

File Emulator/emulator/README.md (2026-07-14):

# Ainekio Body Emulator

This directory owns the protocol-v1 body behavior required by System
Specification v1.0. It is separate from `Emulator/sesame-robot-sim`, which is
an optional visual motion renderer and does not make protocol or safety
decisions.

The emulator implements the complete A-series body surface: handshake and
reconnect, protocol lifecycles, portable-C safety, bounded queues and direct
stop, states and profiles, calibration, camera/microphone/speaker media, battery
cutoff/recovery, LittleFS-equivalent assets, display timing, deep sleep, and
fault injection. All 19 required motion routines can be sent to the optional
Sesame renderer. Protocol `look` still returns an explicit unavailable response
because v1 does not map yaw/pitch to the frozen eight-joint contract.

Build the host bridge to the portable C core:

```sh
cmake -S Emulator/emulator -B build/emulator
cmake --build build/emulator
```

Run the body emulator after setting the same local development token used by the
gateway:

```sh
export AINEKIO_ROBOT_TOKEN='local-development-token'
PYTHONPATH=Emulator:Slave/software python3 -m emulator.body
```

Calibration limits and named poses are committed atomically to
`build/emulator/calibration-v1.json` by default. Use `--calibration-file` to
select another generated runtime path.

Install the pinned host-only WebSocket dependency from
`Emulator/requirements-host.txt`.
It is not linked into ESP32 firmware and does not affect the firmware flash
budget.

`backends/sesame.py` translates accepted protocol-v1 motion into optional Sesame
renderer messages. `backends/sesame_shim.py` owns the local HTTP/SSE renderer
transport. A motion request completes only after the browser reports that the
command was handed to the Sesame UART runtime; publication alone is not reported
as protocol `done`. Neither module is imported by ESP32 firmware.

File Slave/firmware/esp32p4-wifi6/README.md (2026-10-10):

# ESP32-P4-WIFI6 body firmware

Native V2 body-controller target (`0.8.0-p4-color-face`). It uses the portable Ainekio lifecycle,
configuration store and command decoder, with its own P4 startup, board resources,
C6 networking and PCA9685 output driver. It does not compile the S3 platform.

With a saved joint mapping, normal power-on enables PCA9685 channels 0–11 at their home pulses,
starting channels 200 ms apart and continuing to hold the resulting pose.
Default home is **1300 µs at nominal 50 Hz** on every body channel. Channels
12–15 remain off. Startup does not require Wi-Fi or a gateway connection.

This is the electrical assembly reference, not a calibrated chassis-supported
resting pose. The owner has updated the laying pose in the saved Blender scene
`ainekio-variable-gait-Recovery.blend` and exported it to the model's
`motions/gestures/rest/` source on 2026-09-22. Its endpoint has the chassis base
plate grounded and all four lower legs horizontal. Horn
indexing, joint mapping and pulse calibration must connect this geometry to
the actual body. The previously flashed assembly firmware still uses midpoint
pulses; updating geometric source alone does not change those home settings.
The current source integrates twelve-joint operator calibration, provisioning,
profiles/power states, removable storage, OV5647 camera, onboard ES8311 audio,
VAD and the shared wake-word engine. Readiness comes from the actual driver and
asset state. The current assembly uses a **0.96-inch SSD1306 I2C OLED** on
GPIO20 (SCL) and GPIO21 (SDA), selected by default in `sdkconfig.defaults`.
It renders the same face choices and connection guidance in 128×64 monochrome.
The temporary OLED implementation is isolated in `main/display_ssd1306.c`;
normal firmware builds with the current configuration include it, so flashing
other P4 changes retains the working display. Existing local `sdkconfig` files
can retain an older panel choice; confirm `CONFIG_AINEKIO_DISPLAY_SSD1306=y`
before building or flashing this assembly. The 1.9-inch ST7789 RGB565 LCD remains selectable with
`CONFIG_AINEKIO_DISPLAY_ST7789` when its replacement arrives. Its wiring and
expression guide is [here](../../../docs/v2-12servo/LCD_FACE.md). A build
selects one display driver, and the OLED source can be removed when retired.

While a microphone utterance is open (wake, VAD or Open gate), the display overlays
its animated Listening expression. It restores the underlying manual/motion face
when capture closes, including when speaker playback interrupts capture.
The sole body output owner also moves the physical front shoulders (model joints
6 and 9) by +6° over 300 ms, holds while capturing, then returns to the exact
previous commanded pose and pulses. The saved joint-speed limit can lengthen the
transition. Carrier/crank geometry is unchanged. Normal motions take priority;
calibration/manual targets supersede the cue, and existing Stop/disconnect/output
state ownership remains in effect. This feedback never arms detached outputs.

Speaker playback suspends both wake inference and microphone transmission from
TTS/asset start through the existing 800 ms post-playback interval. Wake history
and microphone pre-roll are flushed at playback boundaries. Results from an
in-flight inference are checked again before entering the recording FIFO, so a
speaker start during inference cannot open a stale recording. Dashboard input
telemetry distinguishes listening, capturing and speaker playback. Speaker DMA
writes release the media mutex so incoming audio and status callbacks can run;
cancellation invalidates the write and mutes it before another playback starts.

Body Control's Apply microphone button saves the microphone on/off choice,
Open/VAD/Wake mode and input gain on the P4. These survive power cycles and
controller reconnections; disconnect, sleep and speaker playback suspend capture
without changing the saved choice. Wake enable/model/sensitivity remain saved
by the separate wake settings control. Existing firmware installations retain
their gain and wake settings; apply the microphone choice once after upgrading
to save the formerly temporary on/off and mode settings.

The Audio section exposes microphone gain (0–42 dB in 6 dB steps) and wake
sensitivity (0–100%). Higher sensitivity lowers the model's
probability threshold; gain amplifies the captured signal. Input level is
reported before the wake/VAD gate, so tuning does not require a successful wake
first. The current settings are read back from the robot; changes take effect
without rebooting. The saved gain and
threshold are separate `p4_media` NVS keys, preserving existing wake preferences.

The body executes Stand, CAD Neutral, algorithmic walk/crawl (forward, backward,
left and right), and every gesture compiled from the model catalog. Fixed-angle
turn clips are no longer included in V2. Body Control
builds its pose buttons from the firmware's advertised commands. Walking supports
finite cycles, continuous operation, speed or independent stride/rate updates,
and Finish at the existing gait boundary. See the
[model implementation](../../software/models/v2-12servo/README.md) for the current
catalog, timing and source provenance. Finite commands hold their terminal pose;
Dead's optional preview recovery is excluded.

Current source advertises `walk_steering_v1` alongside `walk_controls_v2` for
the existing paired `forward`/`turn` decoder and gait owner. Both are finite
percentages from −100 to +100: positive forward advances, positive turn turns
left. An update ACK confirms admission and leaves the original action running;
only its terminal result ends that action. See the
[negotiated steering contract](../../software/protocol/README.md#directional-locomotion-and-automatic-run).
Older firmware lacking this feature receives no composed steering from the
gateway. Native decoder/model tests cover this source contract; this change has
not been cross-compiled, flashed or tested on a physical body.

All execution uses the existing body output task and device joint calibration.
Entry follows a coordinated carrier/crank path from a commanded reference; this is not measured shaft position. Conservative continuous path bounds and actual linkage closure are checked before execution; the provisional angle envelope is not a runtime dependency. When outputs are off or only some assigned joints have been commanded, a new motion request first engages the saved Home pulses 200 ms apart, then enters the requested motion. Save and reconnection alone leave outputs off. An invalid model reference is reported explicitly before enabling outputs; changing firmware defaults never rewrites measured Home pulses or model angles.
Clip angle envelopes are checked before movement, and every emitted pulse must
fit the PCA9685 timer capacity. An unrepresentable pose returns LIMIT without
silently compressing its geometry. Nominal calibration does not establish horn
alignment or make every modeled pose physically reachable. STOP, controller loss
and output faults cancel execution; reconnection alone does not resume it.

The robot-specific controller uses float circle intersections and two compact
sole profiles (101 Walk/Run vertices, 90 Crawl vertices), with at most four
endpoint evaluations per leg. It rejects unreachable geometry and retains the
linkage branch. No iterative multijoint solver, line search, support tree or
runtime research search bounds remain. Detailed CAD geometry and Python fitting
stay on the workstation. Contact integration retains its bounded substeps and
fixed stance anchors. Run Finish honors already committed airborne landings
before deceleration, including explicit Run after speed changes.

Finite motion playback uses verified cubic segments instead of dense 120 Hz
arrays. Continuous fitting error is bounded to 0.005 degrees before float
rounding; all recorded extrema, holds, endpoints and command durations remain.
The compiler emits clip extrema so startup does not scan every recorded frame.
The body output owner retains the last successfully written model pose alongside
its pulse frame. Automatic motion entry does not invert rounded PWM; manual
calibration pulses establish their literal reference once. Mapping changes and
output faults invalidate the cached model reference. No NVS layout, saved pulse,
channel, inversion, Home angle or us/degree scale is changed.

The existing Stop, generation fencing, output owner, 20 ms cadence and independent
40 ms progress guard remain. The update path uses fixed storage, with no heap
allocation, storage writes or media processing. Console `controller` reports
observed maximum calculation/frame/request time, over-budget counts, body stack
headroom and internal heap. These measurements are observations, not guaranteed
bounds under untested media workloads. See the model's
[controller validation](../../software/models/v2-12servo/CONTROLLER_VALIDATION.md)
for resource costs, removed components and qualification limits.

The current source build is `0.8.0-p4-color-face`; prior deployment records below refer to `0.6.1-p4-motion`. It requires the 8 MiB application partition. Boards still using
the old `0.3.0-p4-turns` partition layout require the migration described in the
[integration record](../../../docs/v2-12servo/MOTION_INTEGRATION_20260917.md),
not just an application-only flash.

## IMU foundation

The [portable IMU component](../../software/imu/README.md) is compiled by the P4
project and exercised by its native test project. It defines timestamped samples,
calibrated sensor-to-body transforms, attitude estimates and freshness/recovery
flags using pinned x-io Fusion sources. It does not start acquisition, transmit
IMU telemetry or modify movement. Wiring, mounting calibration, the sensor driver
and physical timing measurements are the next integration step. The existing
motion/output owner and motion library are unchanged by this component.

## Shared camera streaming and snapshots

The camera owner multiplexes preview JPEGs and correlated stills in one task.
Espressif `esp_video` / `esp_cam_sensor` control CSI and the OV5647, `esp_ipa`
controls the P4 ISP, and ESP-IDF's hardware JPEG encoder compresses the images.
RAW10 stays on the P4; Body Control receives JPEGs. Sensor AEC/AGC adjusts
exposure/gain; Body Control selects capture profiles, not individual shutter
or ISO values. The vendor OV5647 ISP tuning remains unchanged.

`camera_profiles_v1` provides independent preview/still settings; the additional
`camera_adaptive_v1` feature enables `snapshot_res: AUTO | 960P | FHD` alongside
QVGA/VGA/XGA. Preview remains QVGA/VGA at 0–15 fps. Still boot default is AUTO;
JPEG quality remains 75. Changing preview settings preserves the still profile
unless `snapshot_res` is supplied. Neither profile is stored in NVS.

Preview uses the 1280×960 binned mode with one-frame exposure. Stills enable
the OV5647's eight-frame night integration range (about 178 ms in 960p, 267 ms
in 1080p); the sensor still chooses the exposure and gain for the light. After
startup/profile changes, stills collect at least eight frames and wait until
measured exposure and gain remain within 1/16 of an anchor for 300 ms. After
four seconds per mode, a changing scene returns the current image marked
unsettled instead of waiting indefinitely. This does not stop robot motion.

AUTO meters in the full-field 1280×960 mode. If settled exposure × gain is at
most 1/30 second at unity gain, it switches to the vendor's **cropped 1920×1080**
mode and settles again; otherwise it returns 1280×960. This is an explicit
initial selection heuristic, not a measured optimum across scenes. Select
960P to keep a consistent full field of view, or FHD to force cropped detail.
The installed camera is mounted upside down. Every emitted preview/still image
is rotated 180 degrees before JPEG encoding, so saved files and all consumers
receive upright pixels. Preview rotation is folded into the existing resize
sampling; native stills reverse their dequeued RGB565 buffer in place before
hardware JPEG encoding. This adds a CPU pass for native stills, with no additional
full-frame allocation or sensor/ISP Bayer-pattern changes. Exposure and gain
behavior is unchanged. Physical capture latency must be measured on the P4.
The existing 256 KiB JPEG transport capacity remains unchanged; a larger
encoded image returns the existing camera failure, without silently lowering
quality. Full 5 MP raw capture and host-side raw processing are not implemented.

Queued stills retain their requested resolution, work with preview disabled,
and emit `fps:0` metadata with their original correlation. A still does not
reset the next preview deadline. Shared encoding and transport can still delay
preview delivery; concurrent throughput and acquisition age require device
measurements. The two capture buffers are resized when the sensor mode changes;
the resize scratch remains 1024×768 RGB565 and JPEG storage remains 256 KiB.
Status `camera_capture` reports counter, actual width/height, `exposure_us`,
`gain_x16` (16 = unity gain, not calibrated ISO), `settle_ms`, and `settled`.
The settling flag describes sensor settings, not a guarantee of image quality.

The native `camera_profiles_and_snapshots` test runs production `camera.c`
against virtual sensor/encoder/scheduler I/O. It covers independent profiles,
zero-FPS snapshots, settling, changing illumination, native mode selection,
preview resumption, cancellation, session fencing, and pixel orientation across
native/downsampled images and mode switches. It does
not establish physical sensor operation, image quality or encoding latency.

Physical check, 2026-10-06: application `0.8.1-p4-camera-face` was flashed at
`0x20000` with esptool hash verification, preserving NVS. Fresh stills returned
1280×960 and forced 1920×1080 JPEGs; measured night exposures reached 177,621
and 266,513 µs respectively. VGA preview used approximately 16–19 ms exposure
in the tested room. A correlated still during preview arrived at native
1280×960 after about 3 seconds, followed by resumed VGA preview about 0.1 s
later. Camera drops remained zero during these checks. The Body Control page
rendered the six snapshot choices and measured capture details without browser
exceptions. Native tests cover the AUTO bright-scene selection; its automatic
bright-scene transition and image tuning across other environments still need
physical comparison. No gait was exercised during the camera checks.

Camera rollback, 2026-10-09: `0.8.14-p4-camera-revert` restores the
pre-controls camera implementation: one-frame automatic preview exposure,
original preview resolutions and JPEG quality 75. It retains the separate
wake-audio snapshot correlation fix and the current full robot application,
including the SSD1306 OLED driver. It does not advertise `camera_controls_v1`;
Body Control hides the experimental manual controls for this firmware.
The previous `0.8.13-p4-camera-controls` trial is withdrawn because long preview
exposure caused motion blur and automatic exposure showed brightness alternation.
The gateway/protocol support remains compatible with other capable firmware.

### OV5647 automatic exposure and ISO

`0.8.16-p4-iso3200` raises the automatic gain ceiling to 32x (ISO 3200
on the same OV5647 scale), as requested. Preview shutter remains capped at
approximately 66.7 ms; shutter and gain both remain automatic. This changes
the ceiling, not a fixed ISO. Other camera and robot functions are preserved.

The published Raspberry Pi V1/OV5647 ISO convention is ISO 100/200/400/800
for overall gains 1/2/4/8. It prefers analogue gain over digital gain. The
[PiCamera ISO documentation](https://picamera.readthedocs.io/en/release-1.13/api_camera.html#picamera.PiCamera.iso)
distinguishes this convention from the standards-calibrated V2 sensor mapping;
it does not establish absolute ISO calibration for this P4/module/lens assembly.
The [Raspberry Pi OV5647 helper](https://github.com/raspberrypi/libcamera/blob/main/src/ipa/rpi/cam_helper/cam_helper_ov5647.cpp)
confirms sensor register gain code = analogue gain × 16 and explicitly accounts
for two unreliable startup/mode-switch frames.

[Raspberry Pi's OV5647 tuning](https://github.com/raspberrypi/libcamera/blob/main/src/ipa/rpi/vc4/data/ov5647.json)
provides exposure-mode curves, noise calibration, black level, white balance,
colour matrices, lens shading and gamma. Its primary normal exposure curve uses
1–8× gains; using the register's entire 1–63.9375× numerical range is not an
image-quality qualification. These parameters target Raspberry Pi's ISP and
must be translated and measured on P4, not copied as a drop-in configuration.
[Espressif esp_ipa](https://github.com/espressif/esp-video-components/blob/master/esp_ipa/README.md)
is the existing P4 owner for noise, enhancement, colour and exposure algorithms.
[OmniVision's OV5647 datasheet, section 4.6](https://docs.arducam.com/Raspberry-Pi-Camera/Native-camera/source/OV5647DS.pdf)
documents exposure convergence, night integration and 50/60 Hz anti-banding.
`0.8.15-p4-auto-iso` keeps the sensor's AEC, AGC and frame-length control
fully automatic. Preview permits exposure up to approximately 66.7 ms instead
of one frame; stills keep their eight-frame range. The automatic gain ceiling
is 8x (ISO 800 on the documented OV5647 scale), rather than 63.9375x.
These limits do not fix either shutter or gain: the sensor meters the scene.
Body Control displays measured exposure and ISO-equivalent gain. This is the
published sensor convention, not a new absolute ISO calibration. Dim scenes
can remain dark at these limits, and longer exposures can blur motion.
The firmware retains the entire robot application and SSD1306 OLED. It does
not re-enable the withdrawn manual-controls trial. Native tests verify the
control registers and changing readback; real image quality requires a
lighting comparison on the actual module.

Initial USB-powered check of `0.8.15-p4-auto-iso`: application-only flash verified,
SSD1306 reports `driver_ready=1`, saved calibration remains present, and camera
reports zero drops. Twenty VGA preview frames delivered 0.92 fps at the saved
1 fps setting; the longest observed delivery gap was 2.08 s. The dim scene
reached both configured ceilings: 66,567 us and gain code 128 (8x/ISO 800).
It remained underexposed, so this is **not** evidence of qualified image quality
or measured adaptation to changing illumination. The initial post-reboot camera
restore was rejected as stale; reapplying the same saved camera setting started
the stream. No motion command was used. An illumination-change check remains
necessary; the software tests only establish automatic control configuration
and preservation of changing sensor readback.

## Command diagnostics

Body Control saves command results (including the robot's rejection code and
message), dashboard request failures, and robot clock gaps of at least one
second in its existing `operations.jsonl`. The physical launcher uses
`build/gateway/physical/operations.jsonl`; the preceding segment is
`operations.jsonl.1`. Records include robot identity, connection epoch and
command sequence where available, plus walking speed and gait for correlation.
Pairing tokens and Wi-Fi/setup passwords are excluded from these records.

P4 status and execution failures include `output_timing` (last and maximum I2C
call duration in microseconds, transfer/failure counts, and the existing timing
budget and last failed ESP-IDF result, retained until the next failure/reboot),
`motion_timing` (existing calculation/frame/request maxima and the
output queue depth), and `controller_queue_depth`. Maxima and counts are since
boot. Serialization runs in the controller tasks, outside the servo output
loop. These observations retain the existing clock and I2C deadline rules.
The serial console also includes ESP-IDF's I2C failure messages, distinguishing
hardware NACKs from hardware/software timeouts without logging each frame.

The eight-entry controller queue and one-entry output queue buffer work between
tasks. They are not a playlist that waits for each entire motion to finish:
walking updates adjust the active walk, and a new motion can replace it. The
gateway's fresh-clock check happens before a command reaches either robot
queue; an I2C deadline failure happens while the robot executes it.

## Build and flash

Use ESP-IDF **5.5.4**. The tested board is P4 **revision 1.3**, 32 MiB flash and
32 MiB PSRAM. `sdkconfig.defaults` explicitly selects pre-3.0 silicon. Recheck
revision before using this configuration on another board.

The manifest and lock pin `esp_hosted` **2.12.8**, `esp_wifi_remote` **1.6.4** and
`esp_websocket_client` **1.7.0**. The C6 runs the matching Hosted **2.12.8** slave
from the same resolved package, with its own committed dependency lock. Both
sides use SDIO packet mode. No vendor library patches are required.

From the repository root, after installing ESP-IDF 5.5.4:

```bash
source /home/greggles/esp/esp-idf-v5.5.4/export.sh
cd Slave/firmware/esp32p4-wifi6
idf.py -B build -D IDF_TARGET=esp32p4 -D AINEKIO_C6_IMAGE= build
idf.py -B build -p /dev/serial/by-id/usb-1a86_USB_Single_Serial_5B90184020-if00 -b 460800 app-flash
idf.py -B build -p /dev/serial/by-id/usb-1a86_USB_Single_Serial_5B90184020-if00 monitor
```

The IDF install and serial paths above are the bring-up workstation's paths;
substitute the actual installation and device on another machine. A C6 update
is only available when a real image is embedded. Run `net c6-update` once if the
installed C6 does not match, then verify its reported version after reboot.
The updater latches maintenance/disarm, streams the image through Espressif's
SDIO OTA API and restarts. Failed updates remain in maintenance until reset.
The installed C6 already reports 2.12.8; normal P4 flashes need no C6 rewrite.
Embedding its updater is a separate maintenance operation: run
`bash tools/build_c6.sh`, then build with
`-D AINEKIO_C6_IMAGE="$PWD/build/c6/network_adapter.bin"` when that update is needed.
The normal build clears this cached option to omit the unused updater payload.

`partitions.csv` assigns NVS at `0x9000`, PHY at `0xf000`, and an 8 MiB app at
`0x20000`. P4 configuration uses namespace `p4_config` and the existing staged
two-slot store. There is no automatic NVS erase. Back up occupied flash before
changing another board's partition layout. Build outputs and credentials are
ignored, and must not be committed.

## Resource ownership

`main/board.c` creates the PCA bus and owns OE. Consumers receive its output
driver; they never create a second bus or write OE directly.

| Resource | Assignment / reservation |
| --- | --- |
| PCA9685 | I2C controller 1, SDA GPIO2, SCL GPIO3, address `0x40`, 400 kHz; OE GPIO4 |
| Face display | Current OLED: SDA GPIO21, SCL GPIO20, VCC 3V3, common GND. Alternative ST7789 LCD: SPI2 SCLK20, MOSI21, CS22, DC23, RESET26; VCC and BLK on 3V3. Select the connected panel in menuconfig. |
| Header reference | With USB-C at top, component side facing you: GPIO2=L15, GPIO3=L14, GPIO4=L12, GND=L13, 3V3=R5. L/R are top-down guide row IDs; see the [pinout and wiring guide](../../../docs/v2-12servo/PCA9685_WIRING.md). These correspond to schematic U10 pins 15/14/12/13/36. |
| Onboard codec/camera I2C | GPIO7/8 reserved; no competing legacy I2C driver |
| C6 SDIO | CLK18, CMD19, D0–D3 14–17, reset54; C6 boot6 reserved |
| Debug console | UART37/38 through CH343P and the board's Type-C connector |
| Native USB HS | P1 four-pin MX1.25 connector reserved: 1=VCC_5V, 2=D−, 3=D+, 4=GND |
| Other reserved resources | USB FS GPIO24/25, boot35, SD39–45, codec/I2S9–13 and PA53, MIPI camera/display lanes |

The [Waveshare schematic](https://files.waveshare.com/wiki/ESP32-P4-WIFI6/ESP32-P4-WIFI6-datasheet.pdf)
routes Type-C to CH343P, and P1 to native USB. P1's 5 V pin joins the board power
rail. Future Q6A USB must resolve VBUS isolation/power ownership before connecting
two powered boards. Native USB is reserved; no USB command implementation exists.
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

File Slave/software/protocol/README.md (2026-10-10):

# Ainekio Protocol v1

This directory owns the machine-checkable Ainekio wire contract. It is shared by
the gateway, emulator, host tests, and firmware tests.

`schemas/control-v1.schema.json` is the language-neutral JSON control contract.
It follows section 3 of `docs/Ainekio - System Specification v1.0.docx` and
allows additional fields on known messages for forward compatibility. Semantic
rules that standard JSON Schema cannot express are named with
`x-ainekio-rules` and remain mandatory in every implementation.

`control_v1.py` is the host Python validator for that contract. Protocol errors
raise `ProtocolValidationError`; they never partially execute a command.
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

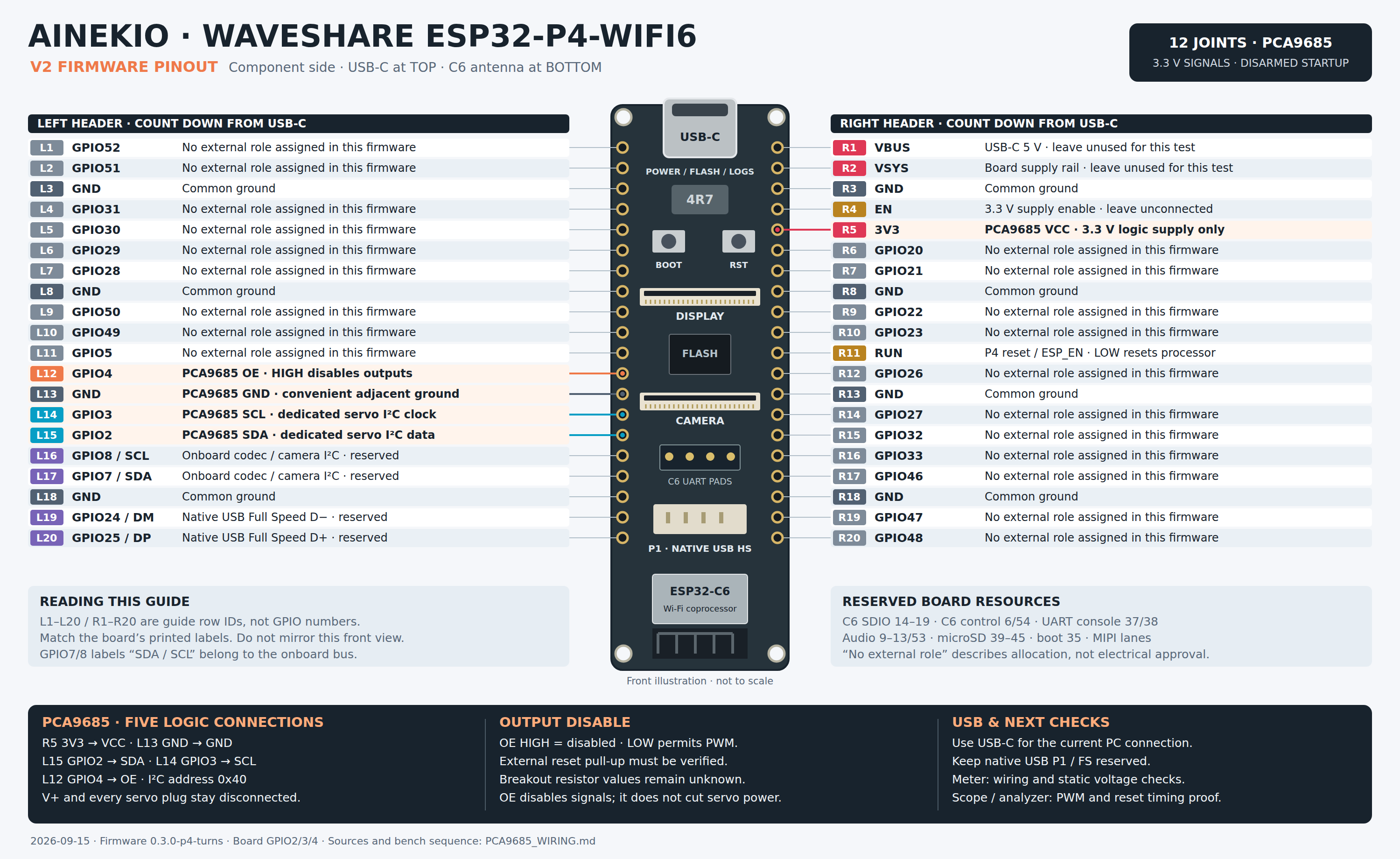
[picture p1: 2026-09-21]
docs/v2-12servo/ESP32P4_Pinout.png

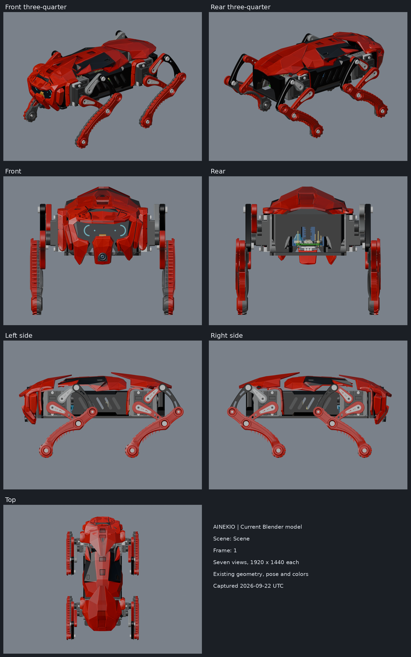
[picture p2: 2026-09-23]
docs/v2-12servo/reference images/overview.png

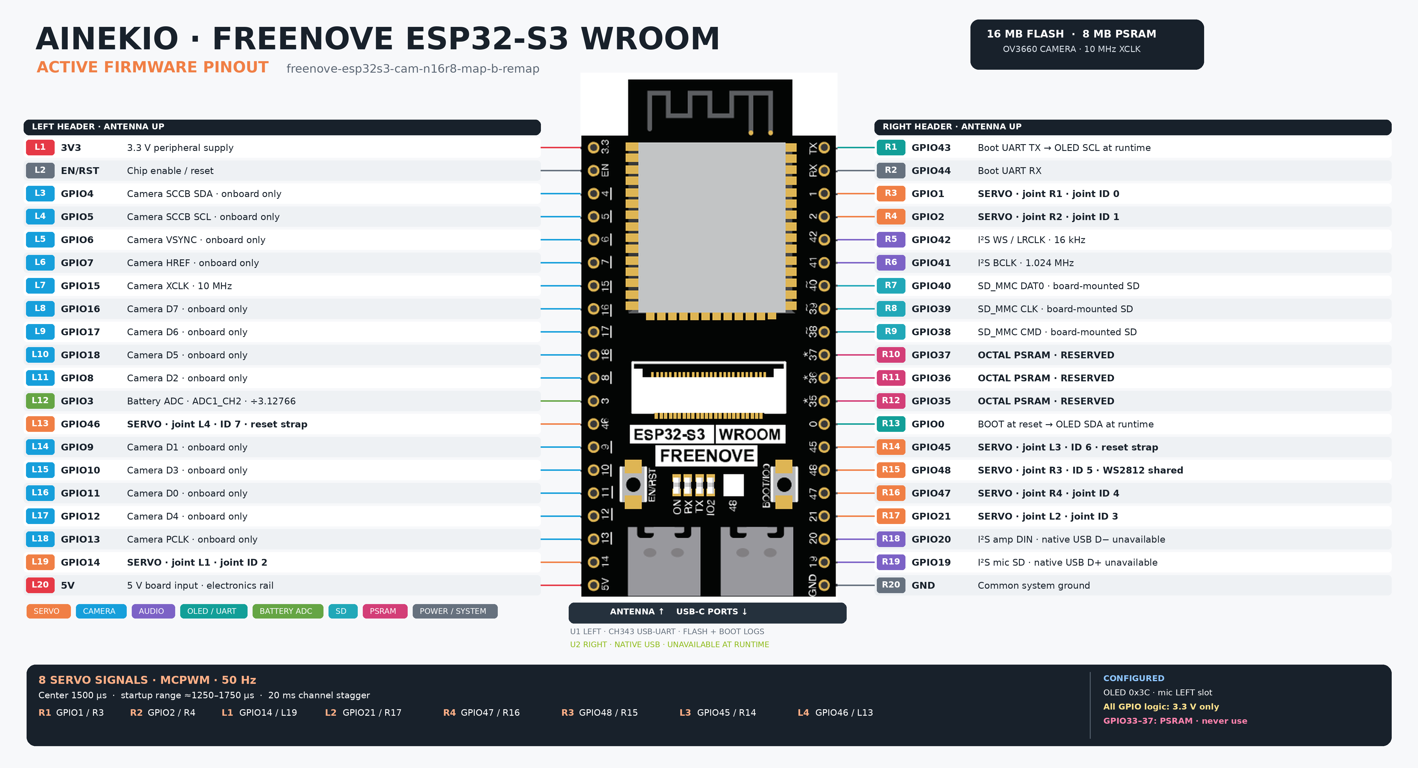
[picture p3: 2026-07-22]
docs/ESP32S3_Pinout .png

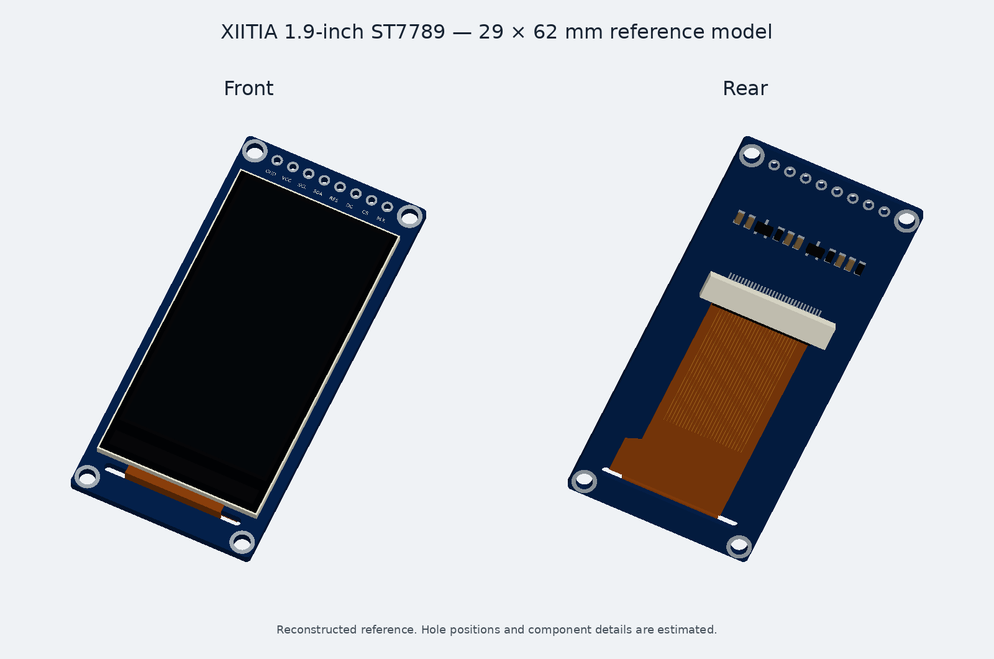
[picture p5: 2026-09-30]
Slave/hardware/v2-12servo/XIITIA_1p9_Display_Reference_Model/preview.png

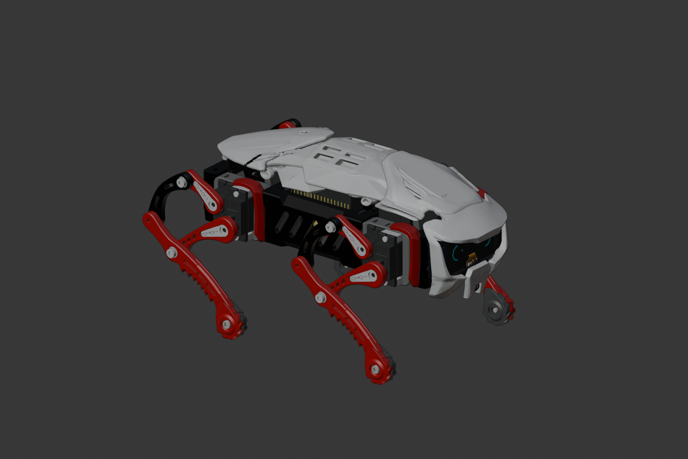
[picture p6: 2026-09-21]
Slave/hardware/v2-12servo/wip-images/01-front-three-quarter.png

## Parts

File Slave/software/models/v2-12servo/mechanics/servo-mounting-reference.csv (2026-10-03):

id | joint | cad_leg | default_channel | recorded_assembly_channel | actuator | home_us | home_model_deg | home_cd | projected_min_model_deg | projected_max_model_deg | provisional_us_per_degree | pulse_at_min_noninverted | pulse_at_max_noninverted
0 | rear_left_shoulder | FL | 0 |  | h_Part002 | 1650 | 0 | 0 | -110 | 110 | 11.11111111111111 | 427.778 | 2872.222
1 | rear_left_carrier | FL | 1 |  | alpha_Part006 | 856 | 1.17 | 117 | -39.99 | 185.33 | 11.11111111111111 | 398.667 | 2902.222
2 | rear_left_crank | FL | 2 |  | theta_Part005 | 723 | -40.41 | -4041 | -53.27 | 139.36 | 11.11111111111111 | 580.111 | 2720.444
3 | rear_right_shoulder | FR | 3 |  | h_Part002 | 1650 | 0 | 0 | -110 | 110 | 11.11111111111111 | 427.778 | 2872.222
4 | rear_right_carrier | FR | 4 |  | alpha_Part006 | 856 | 1.17 | 117 | -39.99 | 185.33 | 11.11111111111111 | 398.667 | 2902.222
5 | rear_right_crank | FR | 5 |  | theta_Part005 | 723 | -40.41 | -4041 | -53.27 | 139.36 | 11.11111111111111 | 580.111 | 2720.444
6 | front_left_shoulder | RL | 6 | 6 | h_Part002 | 1650 | 0 | 0 | -110 | 110 | 11.11111111111111 | 427.778 | 2872.222
7 | front_left_carrier | RL | 7 | 7 | alpha_Part006 | 856 | 1.17 | 117 | -39.99 | 185.33 | 11.11111111111111 | 398.667 | 2902.222
8 | front_left_crank | RL | 8 | 8 | theta_Part005 | 723 | -40.41 | -4041 | -53.27 | 139.36 | 11.11111111111111 | 580.111 | 2720.444
9 | front_right_shoulder | RR | 9 |  | h_Part002 | 1650 | 0 | 0 | -110 | 110 | 11.11111111111111 | 427.778 | 2872.222
10 | front_right_carrier | RR | 10 |  | alpha_Part006 | 856 | 1.17 | 117 | -39.99 | 185.33 | 11.11111111111111 | 398.667 | 2902.222
11 | front_right_crank | RR | 11 |  | theta_Part005 | 723 | -40.41 | -4041 | -53.27 | 139.36 | 11.11111111111111 | 580.111 | 2720.444

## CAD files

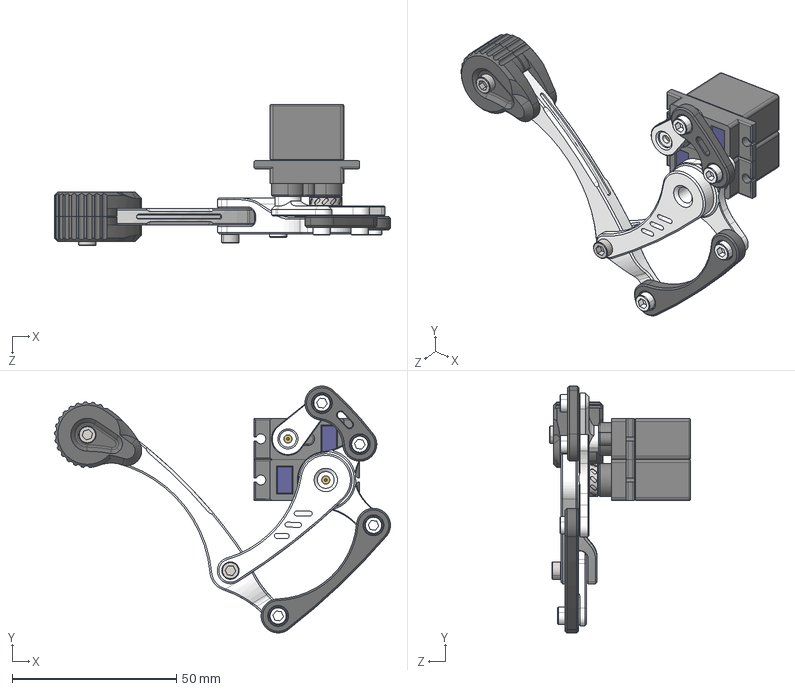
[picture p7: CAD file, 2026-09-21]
Slave/hardware/v2-12servo/Big and small leg assembly-V2.STEP
102.2 x 75.1 x 42.9 mm
SG90嗆儂 x 2
粣創8-12-3.5
大腿套筒
小腿连杆1-V2
小腿连杆3-V2
小腿连杆5-V2
粣創3-7-3 x 5
大腿连杆-V2
小腿连杆2-V2
小腿连杆4-V2
M3-10 x 2
M3-6 x 4
足端拓展件
足端拓展件-镜像

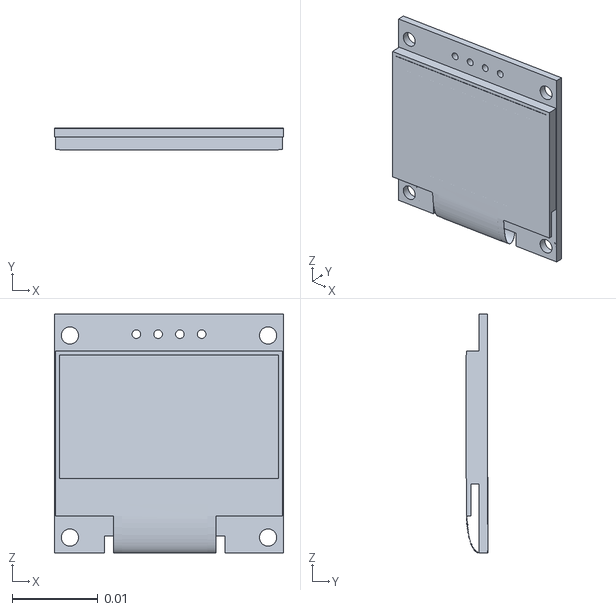
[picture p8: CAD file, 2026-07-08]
Emulator/sesame-robot-sim/source/onshape/assets/oled_128x64_0_96_v1_main.stl
0.0267 x 0.00253 x 0.0279

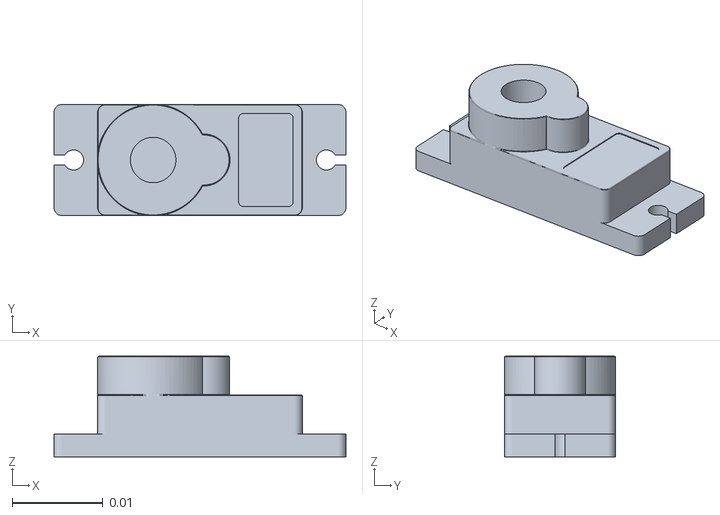
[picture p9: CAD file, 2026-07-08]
Emulator/sesame-robot-sim/source/onshape/assets/sg90_top.stl
0.0321 x 0.0122 x 0.0111

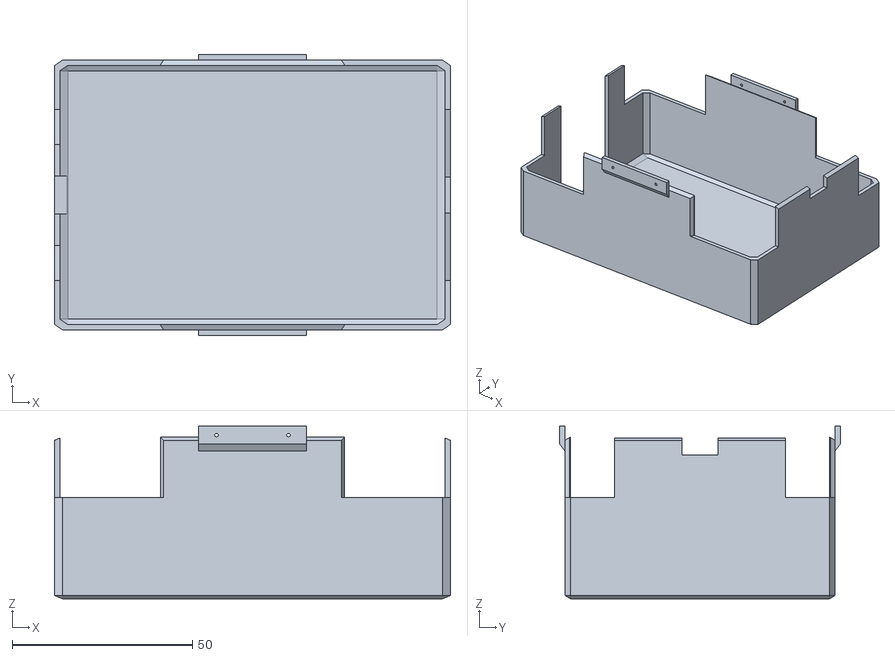
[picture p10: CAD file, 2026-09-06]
Slave/hardware/v1-8servo/3d-print/STL/Frame8.stl
110.0 x 78.0 x 48.0

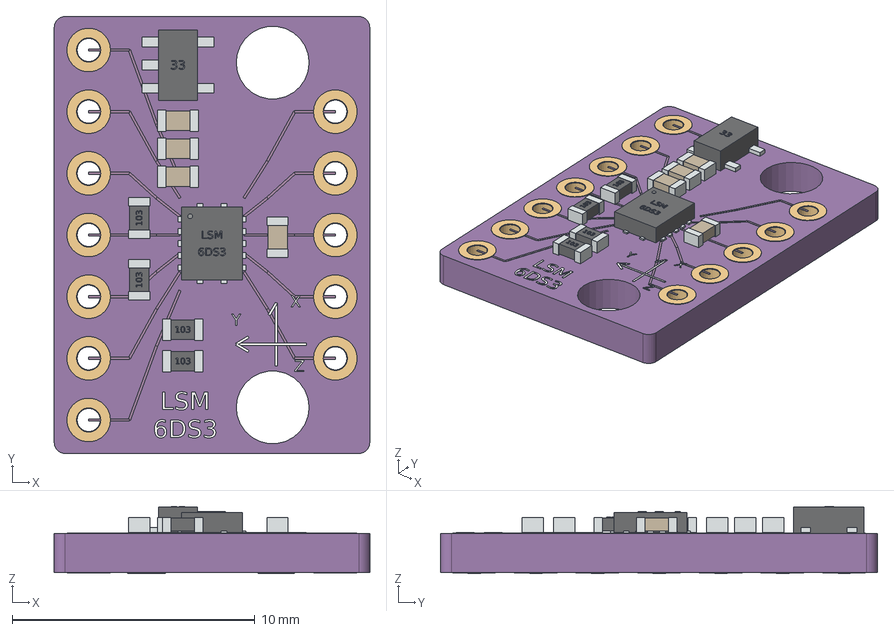
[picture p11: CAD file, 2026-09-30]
Slave/hardware/v2-12servo/GY_LSM6DS3_Two_Hole_Reference_Model/GY_LSM6DS3_reference_no_headers.step
13.0 x 18.0 x 2.77 mm
Purple_PCB_13x18_two_holes_ESTIMATED
Gold_pad_top_1
Gold_pad_bottom_1
Plated_barrel_1
Gold_pad_top_2
Gold_pad_bottom_2
Plated_barrel_2
Gold_pad_top_3
Gold_pad_bottom_3
Plated_barrel_3
Gold_pad_top_4
Gold_pad_bottom_4
Plated_barrel_4
Gold_pad_top_5
Gold_pad_bottom_5
Plated_barrel_5
Gold_pad_top_6
Gold_pad_bottom_6
Plated_barrel_6
Gold_pad_top_7
Gold_pad_bottom_7
Plated_barrel_7
Gold_pad_top_8
Gold_pad_bottom_8
Plated_barrel_8
Gold_pad_top_9
Gold_pad_bottom_9
Plated_barrel_9
Gold_pad_top_10
Gold_pad_bottom_10
Plated_barrel_10
Gold_pad_top_11
Gold_pad_bottom_11
Plated_barrel_11
Gold_pad_top_12
Gold_pad_bottom_12
Plated_barrel_12
Decorative_trace_1
Decorative_trace_2
Decorative_trace_3
Decorative_trace_4
Decorative_trace_5
Decorative_trace_6
Decorative_trace_7
Decorative_trace_8
Decorative_trace_9
Decorative_trace_10
Decorative_trace_11
Decorative_trace_12
Regulator_SOT23_5_ESTIMATED
Regulator_lead_1
Regulator_lead_2
Regulator_lead_3
Regulator_lead_4
Regulator_lead_5
Regulator_mark
Capacitor_top_1_body
Capacitor_top_1_end_1
Capacitor_top_1_end_2
Capacitor_top_2_body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

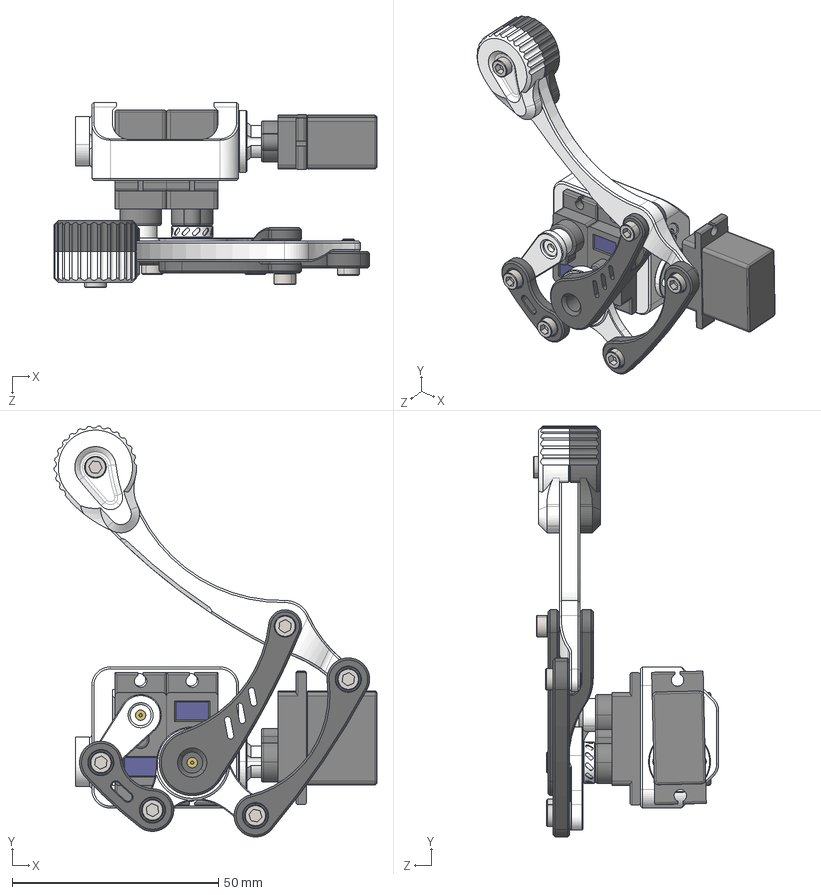
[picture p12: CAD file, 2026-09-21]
Slave/hardware/v2-12servo/Leg model V2.0.STEP
78.2 x 99.6 x 44.9 mm
9g舵机-舵盘
SG90嗆儂 x 3
髋膝舵机连接器 - 镜像
粣創8-12-3.5 x 2
大腿套筒
小腿连杆1-V2
粣創3-7-3 x 5
M3-10 x 2
M3-6 x 4
足端拓展件
足端拓展件-镜像
大腿连杆-V2-镜像
小腿连杆2-V2-镜像
小腿连杆3-V2-镜像
小腿连杆4-V2-镜像
小腿连杆5-V2-镜像

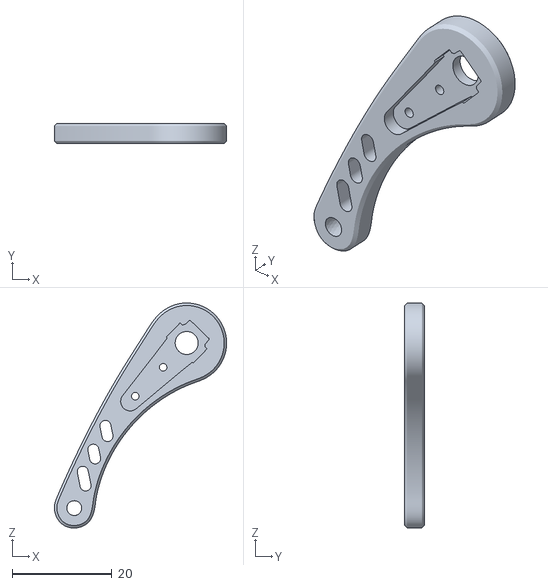
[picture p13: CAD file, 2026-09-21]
Slave/hardware/v2-12servo/STL/newlink/black-parts1/Ainekio-Part023-Continuous-Walking-TESTS Part_023.stl
34.5 x 4.00 x 45.0

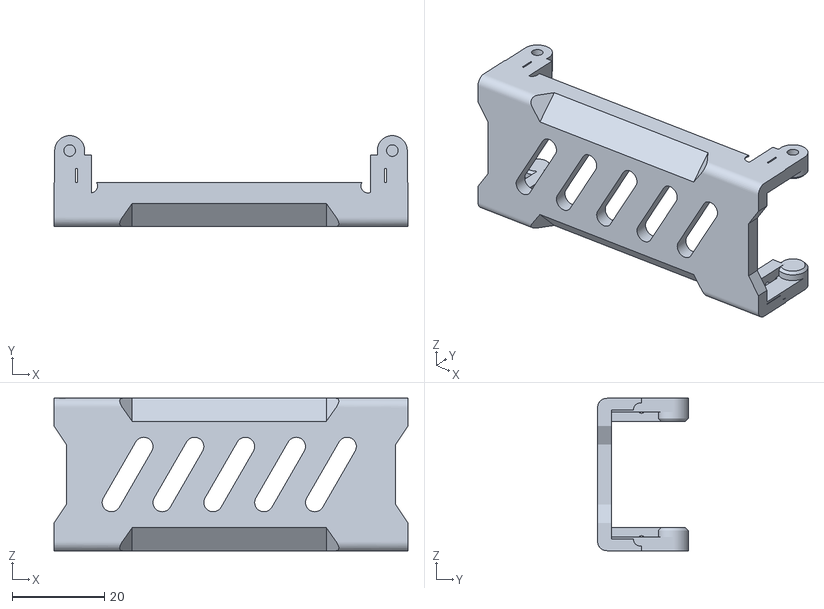
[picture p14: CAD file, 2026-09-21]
Slave/hardware/v2-12servo/STL/newlink/Center_Mount_1/Ainekio-Sit-Bored-TESTS Body - Right Center Mount.001.stl
76.6 x 19.7 x 33.0

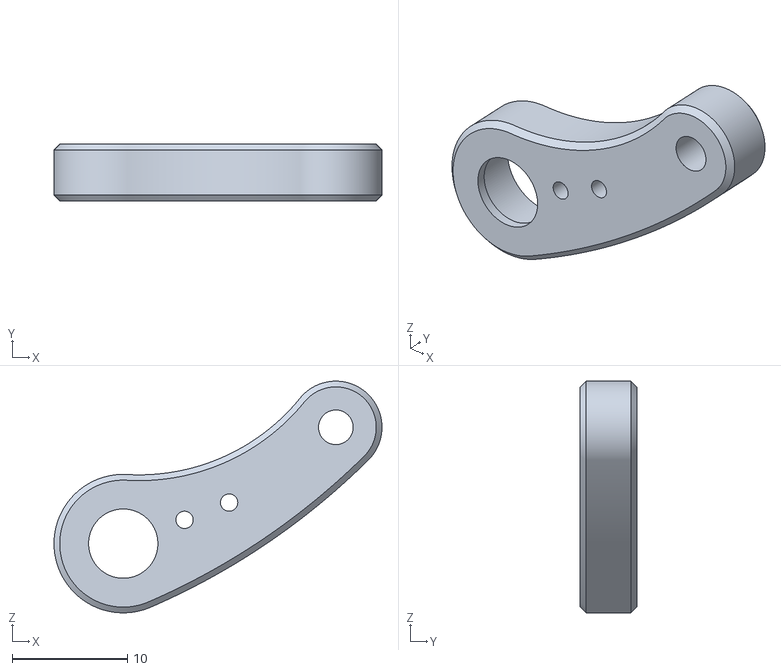
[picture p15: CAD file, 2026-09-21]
Slave/hardware/v2-12servo/STL/newlink/Four-Legs-Matched-Imported-Linkage-REVIEW-Part_009.001.stl
28.4 x 4.90 x 20.1

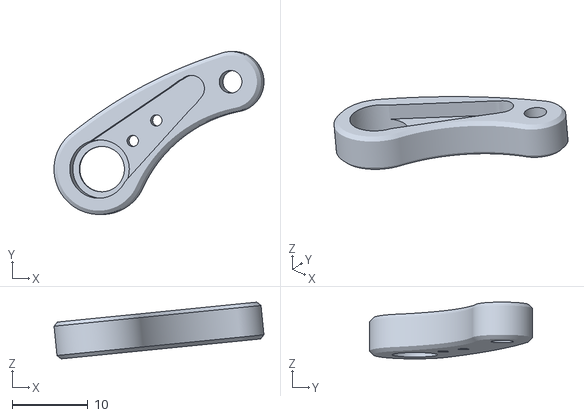
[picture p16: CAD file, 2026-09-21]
Slave/hardware/v2-12servo/STL/newlink/grey parts/Ainekio-Motion-Library-CRAWL Part_009.stl
27.8 x 21.6 x 7.52

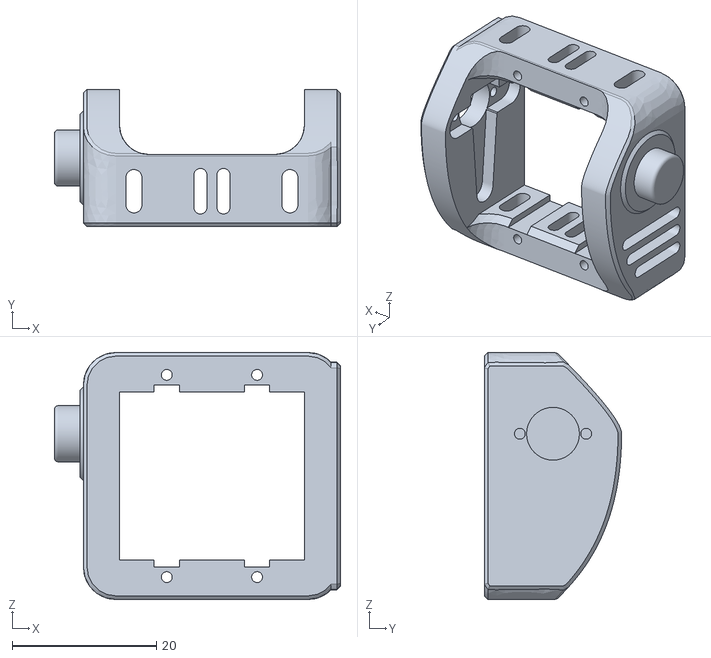
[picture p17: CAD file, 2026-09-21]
Slave/hardware/v2-12servo/STL/newlink/servo_housing_larger_shaft/Ainekio-Dance-TESTS FR - Part_003.stl
39.6 x 19.0 x 34.2

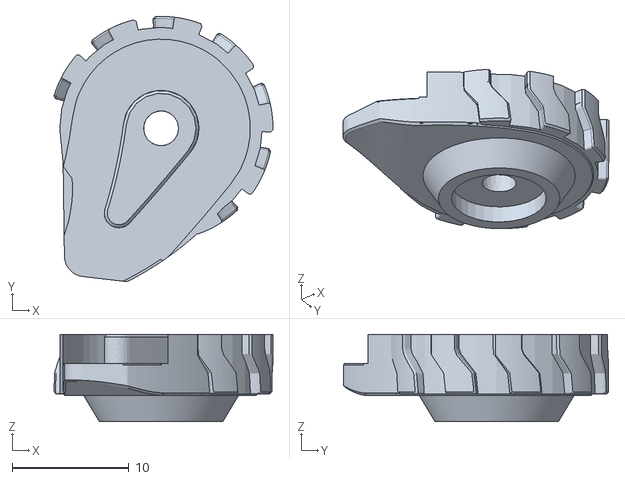
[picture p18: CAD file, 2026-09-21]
Slave/hardware/v2-12servo/STL/newlink/shoe1/FL-Part025-Separate-Collar-REVIEW-Part_020.stl
18.8 x 22.8 x 7.50

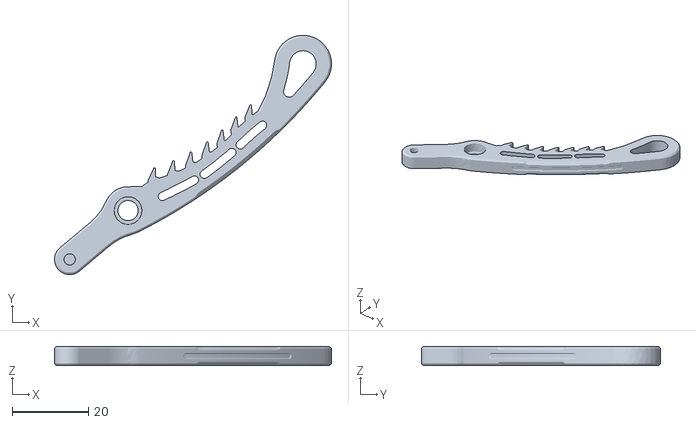
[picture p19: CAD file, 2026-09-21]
Slave/hardware/v2-12servo/STL/newlink/shoe2 - wider_clearace_ver/FL-Leg-Shell-Print-Clearance-REVIEW-Part_027.stl
72.8 x 62.9 x 5.00

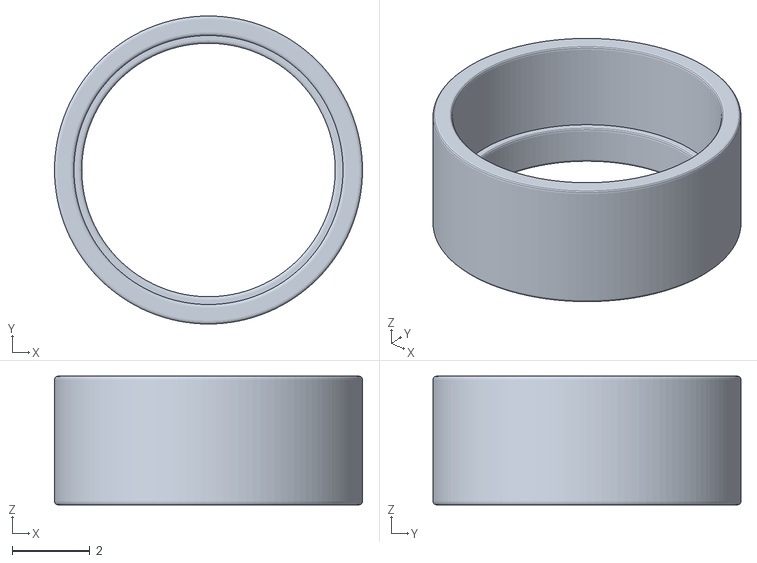
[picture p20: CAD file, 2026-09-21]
Slave/hardware/v2-12servo/STL/newlink/Upper_arm+linkages/part_008-horn-spacer.stl
7.90 x 7.90 x 3.30

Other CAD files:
Slave/hardware/v2-12servo/STL/q6a/ainekio-variable-gait-Recovery-MONITOR Q6A upper corner - right.stl
Slave/hardware/v2-12servo/STL/Red/009_Crank_R_L/ainekio-variable-gait-Recovery-REFINED FL Part_009 - 24mm recessed horn crank - plain joint bore.stl
Slave/hardware/v2-12servo/STL/Red/back plate/ainekio-variable-gait-Recovery-TESTS Body - Rear End Panel - Q6A Ports.stl
Slave/hardware/v2-12servo/STL/Red/back-panel-4-carrier/ainekio-variable-gait-Recovery-STRUCTURAL Rear panel brace - Left.stl
Emulator/sesame-robot-sim/source/onshape/assets/bottom_cover.stl
Emulator/sesame-robot-sim/source/onshape/assets/femur_joint_l1.stl
Emulator/sesame-robot-sim/source/onshape/assets/femur_joint_l2.stl
Emulator/sesame-robot-sim/source/onshape/assets/femur_joint_r1.stl
Emulator/sesame-robot-sim/source/onshape/assets/femur_joint_r2.stl
Emulator/sesame-robot-sim/source/onshape/assets/femurjoint_r2.stl
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

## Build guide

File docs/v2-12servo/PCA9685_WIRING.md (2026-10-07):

# P4 pinout and PCA9685 wiring

Updated 2026-09-22 for firmware `0.4.2-p4-home`. Applies to the selected
**Waveshare ESP32-P4-WIFI6**, with the USB-C socket at the top and C6 antenna
at the bottom when viewing the camera/display connectors. Other P4 boards may
have different layouts.

## Image guides

- [Full P4 pinout — PNG](ESP32P4_Pinout.png) · [editable SVG](ESP32P4_Pinout.svg)
- [P4 → PCA9685 wiring — PNG](PCA9685_Wiring.png) · [editable SVG](PCA9685_Wiring.svg)
- [P4 → 1.9-inch LCD wiring — PNG](LCD_Wiring.png) · [editable SVG](LCD_Wiring.svg) · [LCD instructions](LCD_FACE.md)

The pinout is an original vector illustration checked against Waveshare's
[physical pinout](https://docs.waveshare.com/assets/images/ESP32-P4-WIFI6-details-inter-3472c9ea8e7f1e2665531f8d7e954e06.webp)
and [schematic](https://files.waveshare.com/wiki/ESP32-P4-WIFI6/ESP32-P4-WIFI6-datasheet.pdf).
The wiring diagram is functional: **its PCA9685 terminal order is not a drawing
of the delivered breakout**. Follow the module's printed labels.

`L1–L20` and `R1–R20` are guide row IDs, each counted down from USB-C.
They are not GPIO numbers or Raspberry Pi header numbering. These rows match
the official front view; viewing the underside reverses left and right.

## Five logic connections

**Remove power before adding or moving wires or servo plugs.**

| P4 guide location | P4 printed label / signal | PCA9685 label | Purpose |
| --- | --- | --- | --- |
| R5: fifth right pin from USB-C | `3V3` | `VCC` | 3.3 V chip logic power |
| L13: thirteenth left pin | `GND` | `GND` | Common logic ground |
| L15: fifteenth left pin | `2` / GPIO2 | `SDA` | Dedicated servo-bus data |
| L14: fourteenth left pin | `3` / GPIO3 | `SCL` | Dedicated servo-bus clock |
| L12: twelfth left pin | `4` / GPIO4 | `OE` | Independent output-disable control |

These GPIO assignments are defined in
[`main/board.h`](../../Slave/firmware/esp32p4-wifi6/main/board.h).
The source owns I²C controller 1 at 400 kHz, expects address `0x40`, and configures
nominal 50 Hz PWM. The oscillator and actual waveforms have not been measured.
Do not use the header pins printed **SDA / SCL** (GPIO7/8): those belong to the
onboard codec/camera bus. Use the pins printed **2 / 3** for this driver.

## Servo power and startup

`VCC` powers the PCA9685 logic; `V+` powers servos. Keep VCC on P4 **3V3**.
Do not bridge VCC and V+. Use common ground between the P4, PCA board and servo
supply. The standard breakout's servo ground is the outer row, red/V+ the
middle row, and signal the inner row. With the screw terminal above the servo
rows, channels run from 0 at the left to 15 at the right.

The owner confirmed a servo moving on channel 0 with PC USB feeding P4 and a
P4 5 V-to-PCA V+ jumper. This establishes one-servo operation, not the current
capacity of the P4 header. For multiple servos, remove that jumper and feed
PCA V+ directly from the 5 V servo supply; retain the common ground and all five
logic connections. Do not connect independent +5 V sources together.
See the [PCA9685 power-pin reference](https://learn.adafruit.com/16-channel-pwm-servo-driver/pinouts).

Normal firmware starts channels 0–11 at their saved home pulses, 200 ms apart,
and leaves 12–15 off. Defaults are 1500 µs assembly midpoints; they are not yet
a calibrated laying pose. See [startup and assembly](../../Slave/firmware/esp32p4-wifi6/README.md#startup-and-assembly).
There is no wiring acknowledgement or separate bench firmware to enable first.

## Output enable

OE is active low: HIGH disables PWM and LOW permits it. GPIO4 drives OE high
at initialization and on a stop/fault. OE disables the signal; it does not cut
servo power or establish a safe load current. The generic breakout's default
OE pull-down is accepted for this supervised assembly; firmware cannot guarantee
OE remains high while the P4 is held in reset. No added resistor is required by
the startup procedure. Do not hold reset as a substitute for removing power
while changing wiring. Reset waveform behavior has not been measured.

The earlier owner-reported unpowered readings were OE–GND **9.94 kΩ** and
OE–VCC **43.69 kΩ**. These in-circuit readings are recorded observations, not
acceptance thresholds or a request for further resistance measurements.

## Other connectors to keep clear

- **USB-C:** present PC power/flash/console connection through CH343P.
- **Native USB HS P1:** separate four-pin MX1.25 connector. Schematic numbering:
  1=VCC_5V, 2=D−, 3=D+, 4=GND; match the actual connector/cable orientation,
  not a mating plug's mirrored view. Its power shares the board rail. Future
  Q6A use requires explicit USB roles and power isolation before connection.
- **GPIO24/25:** alternate native USB Full Speed D−/D+, reserved.
- **EN header:** 3.3 V supply enable. **RUN header:** P4 ESP_EN/reset.

Connector roles and routing are checked against the
[manufacturer's hardware description](https://docs.waveshare.com/ESP32-P4-WIFI6#hardware-description)
and schematic linked above. Native USB remains reserved; the current controller
transport is the existing network connection.

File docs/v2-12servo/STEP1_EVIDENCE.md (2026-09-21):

# Step 1: P4 board and output-disable verification

Date: 2026-09-15. **NOT ACCEPTED — electrical evidence incomplete.**

The native target is implemented and flashed. P4/C6 boot, station networking and
real gateway admission have been exercised. The PCA9685 remains disconnected
and unpowered; the owner has a multimeter but cannot take its resistance readings
yet, and has no oscilloscope, logic analyzer or current-limited bench supply.
No PWM, OE voltage/timing, servo movement or power measurements are claimed.

## Actual board and software pairing

| Item | Evidence |
| --- | --- |
| P4 | esptool and firmware both identify **revision 1.3**; 40 MHz crystal, 32 MiB flash, runtime 32 MiB PSRAM at 200 MHz with memory test passing; CPU 360 MHz |
| USB used | CH343P USB-UART, `/dev/serial/by-id/usb-1a86_USB_Single_Serial_5B90184020-if00`, currently `/dev/ttyACM0`; this is not native USB |
| Host | ESP-IDF **5.5.4**, `esp_hosted` **2.12.8**, `esp_wifi_remote` **1.6.4**, WebSocket **1.7.0**, pinned manifest/lock |
| C6 | Built from the pinned Hosted package with its own dependency lock; installed by real SDIO OTA from the P4, then reported **2.12.8** after restart |
| SDIO | 40 MHz, four-bit packet mode on both sides; board's documented pin assignment |
| C6 image | 1,209,600 bytes; SHA256 `43e78006e6c91f3a6024c9492450f32f5b67db36c8a0b73f6666c8c05f3f79f3` |
| Initial Step 1 P4 image | SHA256 `55d7aae00d1b417ac409499030e4b79e17f364b6b04ae25351043f5648d3f46c`; all esptool written-region hashes verified. Superseded by the later turn-integration application flash linked below. |

The factory C6 answered SDIO but reported an unknown 0.0.0 version and failed the
firmware-version RPC. It was replaced using the upstream OTA protocol's version-
dependent activation procedure. No C6 jumper or extra serial adapter was needed.
The vendor 1.4.0/0.14.0 host pair failed against IDF 5.5.4's changed Wi-Fi struct;
the final pair requires no patches to managed dependencies.

Before P4 flashing, bytes `0x000000–0x41ffff` were backed up as
`build/p4-step1/original-0-420000.bin` (4,325,376 bytes), SHA256
`169556daf70649a728555d6c336f588db68baa3c430602585cc343b76ede344e`.
This covers the region occupied by the new layout, not a full 32 MiB flash dump.
NVS/PHY offsets are retained; firmware does not erase NVS on an error.

## Changes and ownership

- `Slave/firmware/esp32p4-wifi6/`: independent startup, configuration/NVS,
  partition layout, resources, C6 networking/update, console diagnostics,
  WebSocket adapter, local output task, watchdog and independent supervisor.
- `components/ainekio_pca9685/` within that target: real synchronous register
  driver, OE gate, explicit recovery/arm and generation fencing; focused tests.
- `Slave/software/core/{include/ainekio,src}/admission.*`: transport-independent
  session/expiry admission composed with the existing command lifecycle.
  Protocol/codec/core and tests add an opt-in operator diagnostic command;
  V1's eight-joint decoder/default behavior remains intact.
- `Slave/software/protocol/`: feature/envelope validation, schema and fixtures.
- `Master/gateway/server/service.py`: negotiated deadlines/model/readiness and
  diagnostic submission using existing authentication/session/result ownership.
  `dashboard/server.py` adds an authenticated operator route;
  `environment_adapter/server.py` suppresses unready motion/media features.
- `Emulator/tests/test_p4_foundation.py`: compatibility, deadlines, correlation,
  capability and validation checks. Documentation records Q6A placement/USB/power
  constraints without creating Q6A services or extracting the broad S3 runtime.

Pre-existing action-receipt, adapter and hardware-layout work in the shared
worktree was preserved. No commit or push was performed for this milestone.

## Build, flash and software checks

Build instructions, including the C6 image, are in the
[target README](../../Slave/firmware/esp32p4-wifi6/README.md#build-and-flash).
The actual final P4 flash command ran from its `build/` directory:

```bash
/home/greggles/.espressif/python_env/idf5.5_py3.12_env/bin/python -m esptool \
  --chip esp32p4 \
  --port /dev/serial/by-id/usb-1a86_USB_Single_Serial_5B90184020-if00 \
  --baud 921600 --before default_reset --after hard_reset write_flash @flash_args
```

The generated arguments write bootloader `0x2000`, partition table `0x8000`, and
P4 app `0x20000` for 32 MiB flash. C6 update used the native `net c6-update` command.
The S3 build was checked with `idf.py -B build build` under its own target and
the same IDF installation; **S3 was not flashed**.

| Check | Result |
| --- | --- |
| Native P4 build | PASS |
| Matched C6 build, including portable `${IDF_PATH}` lock entry | PASS; reproduced same image hash |
| Existing S3 build | PASS |
| Portable C core | **13/13 CTest tests PASS** |
| PCA9685 component | **1/1 CTest executable PASS**, containing initialization/register sequence, failure at every initialization transfer, readback mismatch, interrupted arm/recovery, stale queued work/completions, outstanding-transfer recovery, upper channels, deadlines and late-writer tests |
| Affected gateway/dashboard/adapter/receipt/P4 tests | **83/83 PASS** |
| Python protocol tests | **13/13 PASS** |

Reproduction from repository root:

```bash
cmake -S Slave/software/core -B /tmp/ainekio-p4-core-tests
cmake --build /tmp/ainekio-p4-core-tests -j4
/usr/bin/ctest --test-dir /tmp/ainekio-p4-core-tests --output-on-failure
cmake -S Slave/firmware/esp32p4-wifi6/components/ainekio_pca9685 -B /tmp/ainekio-p4-driver-tests
cmake --build /tmp/ainekio-p4-driver-tests -j4
/usr/bin/ctest --test-dir /tmp/ainekio-p4-driver-tests --output-on-failure
PYTHONPATH=Master:Slave/software:Emulator:Emulator/tests python3 -m unittest \
  Emulator.tests.test_gateway_service Emulator.tests.test_gateway_dashboard \
  Emulator.tests.test_environment_adapter Emulator.tests.test_environment_speech \
  Emulator.tests.test_environment_command_catalog Emulator.tests.test_action_receipts \
  Emulator.tests.test_p4_foundation
PYTHONPATH=Slave/software python3 -m unittest discover -s Slave/software/tests/protocol -v
```

Socket tests require local loopback access. An initial sandboxed run could not
bind sockets; the complete affected suite was rerun with access. The corrected
import path includes `Emulator/tests` for the existing receipt test helper.

## Live board/network evidence

| Check | Observed result |
| --- | --- |
| Startup and software/EN resets | Native firmware boots, reports output `armed=0`, `wiring_verified=0`; absent PCA produces an I2C fault. This is software state, not an OE measurement. |
| Station | Saved NetworkManager profile selected by active UUID and provisioned privately; DHCP gave **192.168.0.89**; C6/P4 established a real gateway connection. Credentials never entered tracked source. |
| Gateway | Existing `GatewayService` on isolated ports, actual P4 over Wi-Fi; token-authenticated session reports model `v2-12servo`, motion/camera/microphone/speaker all false. |
| Commands | Calibration-mode selection ACK; absent-device recovery and unverified-wiring run NAK `unsafe`; unavailable movement/joint calibration NAK `unknown`; STOP ACK. |
| Admission | On-wire expired deadline and wrong epoch both NAK `stale`; a fragmented WebSocket mode message reassembled and ACKed. |
| Session recovery | Suppressed application heartbeats caused disconnect and a new epoch; wrong token was rejected; restoring the configured token established another fresh session. |
| Silence timing | Host observed socket closure **5.077 s** on the final image (earlier run 5.123 s) after its last control send. Socket teardown includes transport work; this neither verifies nor waives the **4.005 s detection / 4.23 s hold-or-disable** requirement. Electrical timing remains pending. |
| Setup AP | Owner joined with a phone/tablet; actual C6 association at 602.648 s and DHCP lease **192.168.4.2** at 603.059 s in `ap-and-recovery.log`. The ten-minute setup window expired and disconnected the client. This proves AP association/DHCP, not a browser portal. |
| Final AP recovery | On the final image, `net ap` enabled the AP; `net retry` stopped it at 15.113 s. At 80 s, station remained connected and AP remained off, beyond the 60 s fallback threshold. Final board status was disarmed/unverified and controller authenticated. |
| Explicit host change | `config controller` switched from port 18790 to a separate existing-gateway instance at 18792 and back. The old connection closed, the new instance began epoch 1 and ACKed mode selection, with no firmware rebuild. Both endpoints were on this computer; no Q6A hardware/service execution is claimed. |
| True cold power cycle | Owner confirmed USB power removal for at least 5 seconds with LEDs off, then reconnection. Without opening serial, the gateway received a new P4 hello at **7.581 s device uptime**, authenticated epoch **5**, and established TCP from **192.168.0.89**. This proves cold-start/network recovery, not reset-time OE behavior. |

Local raw evidence is ignored under `build/p4-step1/`: `first-boot.log`,
`c6-update.log`, `station-boot.log`, `ap-and-recovery.log`, `ap-recovery-final.log`,
`session-check.log`, `session-final.log`,
flash logs and the original-region backup. `provisioning.json` is private mode
0600 and contains secrets; do not publish it or include it in a report bundle.

At the initial Step 1 handoff the temporary observers were stopped, no background
service was installed, and the P4 retained bench port 18790. In the subsequent
owner-requested Body Control integration, its private credential was registered
alongside V1 and the saved controller changed explicitly to
`ws://192.168.0.44:8790/robot`. The existing foreground gateway was restarted
through its canonical launcher with both registrations and its password retained.
The [subsequent turn-integration record](../../Slave/software/models/v2-12servo/motions/turns/README.md#verification-and-application-flash-2026-09-15)
documents application `0.3.0-p4-turns`, read-only on-board samples and the live
authenticated connection. Physical motion remains unavailable; these later
checks do not complete Step 1 electrical acceptance.

## Electrical acceptance: all still pending

The [P4 pinout and PCA9685 wiring guide](PCA9685_WIRING.md) now maps the firmware's
GPIO assignments onto the official physical header layout and gives the initial
multimeter procedure. Creating these guides added no electrical measurements.

The [HUAREW HR-PCA9685 listing](https://www.amazon.com/HUAREW-PCA9685-Interface-Compatible-Raspberry/dp/B0CRV3MK14)
documents an OE pin, 3.3 V controller compatibility and 220 Ω output series
resistors. It does **not** supply the delivered board's OE/SDA/SCL pull-resistor
values or a verified schematic. Another brand's schematic cannot establish this
unit's wiring. The owner confirms soldered headers only.

| Required evidence | Unchanged acceptance target / blocker |
| --- | --- |
| Unpowered wiring | Measure OE↔GND, OE↔VCC, SDA↔VCC, SCL↔VCC; confirm labels, common ground and pull-up/pull-down topology. Owner cannot take readings yet. |
| Logic voltage/reset bias | PCA VCC and I2C must use 3.3 V logic. Verify OE stays high with P4 reset/unpowered and PCA powered; resolve conflicting resistors/backfeed. No voltage or resistance readings yet. |
| Normal PWM | Measure nominal 50 Hz period and commanded pulse widths on channels 0 and 11, with 12–15 inactive; internal oscillator tolerance remains uncalibrated. No scope/analyzer. |
| Transfer timing | ≤5 ms entire armed transfer including scheduling; actual 400 kHz waveforms/ACK and completion evidence required. A 5 ms API argument is not proof. |
| Direct disable / observed I2C error | Inactive servo signal ≤1 ms after gate entry / observed error. Requires a correlated entry/error timing marker and OE/PWM capture. |
| Hung bus | Inactive output ≤15 ms after transfer begins; inject a controlled SDA/SCL fault and record transfer plus OE/PWM, without shorting a power rail. |
| Interrupted arming / late completion | No enable pulse after disable, including real multicore timing and outstanding transfers; `interrupt_arm` exercises the real write-before-enable boundary. Software races pass, electrical trace missing. |
| Motion-progress stall | 20 ms update, fault at 40 ms, supervisor every 5 ms, inactive output ≤50 ms since last completed frame; `stall` diagnostic available but not run against hardware output. |
| Watchdog / resets | 100 ms progress watchdog configured with panic/reset. Whole-MCU inactive output ≤250 ms; capture cold start, software/watchdog reset, brownout and independent P4 reset with PCA rail held up. No proven reset bias, trace or controlled supply. |
| MG90 pulse loss and loaded power | Later Step 3 prerequisites: actual servo variant, pulse-loss response, current, wiring/connector capacity, rail sag and supported-leg mechanics. No servo has been powered by this milestone. |

Required equipment: a scope for voltage/transient evidence, a logic analyzer or
scope with enough simultaneous channels for OE/PWM/SDA/SCL (10 MS/s or better
for the 400 kHz bus), and a current-limited adjustable supply for controlled
power sequencing/brownout checks. Whole-MCU and ≤1 ms entry-response tests also
need a correlated timing marker/trigger; console timestamps alone are inadequate.
A multimeter can establish static wiring/voltage, not absence of brief pulses.

Next electrical sequence, once the meter is available:

1. Leave everything unpowered, all servo plugs/V+ disconnected; obtain the four
   resistance readings and verify the delivered breakout's labels.
2. Resolve a real external OE pull-up to 3.3 V against those readings. No resistor
   value is accepted by assumption. With PCA powered and P4 held reset, verify
   disabled bias before connecting live signal tests.
3. Confirm the board header orientation before wiring GPIO2→SDA, GPIO3→SCL,
   GPIO4→OE, 3.3 V→VCC and GND→GND. Leave V+ and servos disconnected.
4. Measure VCC, OE and bus idle levels; capture reset/boot behavior. Only then
   acknowledge `wiring verified-no-servos` and explicitly recover/arm a bounded
   diagnostic through the authenticated gateway.
5. Capture the required normal/fault/reset traces with test conditions and
   measured maxima. Failed targets remain failures until explicitly resolved;
   complete this proof before broad shared-runtime extraction.

The AP test exposed a target integration bug: after setup ended, an existing
station address did not produce a new GOT_IP event, leaving provisioning waiting
and reopening the AP after 60 seconds. The final target reports its current
station link to the existing provisioning state machine each cycle; that machine
retains manual AP operation until its requested exit. The final `net retry`
recovery check passed beyond that 60-second threshold; the final image's complete
ten-minute automatic-expiry cycle was not rerun.

The optional Q6A's USB routing, power isolation, thermal and chassis-load budgets
are specified in [the firmware design](FIRMWARE_DESIGN.md#controller-admission-and-optional-q6a-deployment).
No Q6A services, USB transport or numeric power/load margins are claimed ready.

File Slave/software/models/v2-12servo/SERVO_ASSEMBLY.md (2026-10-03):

# V2 servo mounting and calibration

Profile `v2-24-38-centered-shaft-heads`. The original motion geometry and timing are retained. The retained mapping references below are provisional; they do not establish the installed horn angles.

| Joint | Part | Default Home reference (non-inverted) | Model angle at that pulse |
| --- | --- | --- | --- |
| Shoulder | Part 002 / 003 | 1650 µs | 0° |
| Carrier | Part 006 / 023 | 856 µs | 1.17° |
| Crank | Part 005 / 009 | 723 µs | -40.41° |

The owner reports 300–2900 µs crank travel. The original motion curves are retained. The attempted whole-library recentering was removed because it changed the physical leg poses. Home pulse and model angle must describe the same physical joint pose; fitting waveform extrema inside a pulse span does not establish that relationship.

The mapping assumes non-inverted direction and 11.111111 µs/degree. Actual shaft travel, spline alignment and installed direction remain unmeasured. All four legs use the model angles in their own CAD frame. Physical rear legs are CAD FL/FR; physical front legs are CAD RL/RR.

Body Control remains the owner of channel, Home pulse, Model angle at Home, inversion and scale. Firmware defaults do not overwrite saved calibration. Physical joint angles at the saved Home pulses remain unmeasured. Correct physical mapping must be established before claiming installed motion parity.

| ID | Physical joint | CAD leg | Default channel | Home µs | Model angle |
| --- | --- | --- | --- | --- | --- |
| 0 | rear left shoulder | FL | 0 | 1650 | 0° |
| 1 | rear left carrier | FL | 1 | 856 | 1.17° |
| 2 | rear left crank | FL | 2 | 723 | -40.41° |
| 3 | rear right shoulder | FR | 3 | 1650 | 0° |
| 4 | rear right carrier | FR | 4 | 856 | 1.17° |
| 5 | rear right crank | FR | 5 | 723 | -40.41° |
| 6 | front left shoulder | RL | 6 | 1650 | 0° |
| 7 | front left carrier | RL | 7 | 856 | 1.17° |
| 8 | front left crank | RL | 8 | 723 | -40.41° |
| 9 | front right shoulder | RR | 9 | 1650 | 0° |
| 10 | front right carrier | RR | 10 | 856 | 1.17° |
| 11 | front right crank | RR | 11 | 723 | -40.41° |

## Motion paths

Full Walk uses 92 mm planted sweep. Forward Run retains 104 mm, with coordinated body pitch and foot timing. Starts, control changes and Finish follow the same native planner. All original recorded joint curves are retained. Named motions and entry transitions use the same existing affine mapper; numerical curve parity alone does not prove physical motion parity.

The internal model includes 4 mm diameter × 1.5 mm shaft screw heads, captured moving linkage meshes and stationary Part 003/005/006 on all four legs. It does not establish cable clearance, print tolerances, torque, tracking or balance. A surface-intersection check is modeled evidence, not a physical collision guarantee.

The profile records connected carrier/crank limits. These are coupled: independent extrema cannot be combined arbitrarily. Shoulder-to-body and leg-to-leg clearance require separate evidence. The existing PWM capacity and joint-speed policy remain unchanged. No additional runtime limiter is introduced.

Home is an operator-selected literal pulse; its model association is independently configurable. CAD Neutral, Stand, Sit and Rest remain distinct model poses. Updating source does not flash firmware, change NVS calibration or command physical motion.

See [the current range audit](mechanics/original-motion-range-audit.md), [the joint table](mechanics/servo-mounting-reference.csv) and [the canonical profile](servo_profile.json).

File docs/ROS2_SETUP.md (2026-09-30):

# ROS 2 development environment

This records the desktop-first ROS setup and the owner's portability requirement.
ROS installation does not integrate Ainekio with ROS: the robot adapter, IMU
feedback, vision nodes, and Q6A deployment remain separate implementation work.

## Common baseline

Use ROS 2 Jazzy with an Ubuntu 24.04 (Noble) userspace. Upstream provides both
amd64 and arm64 packages and supports Jazzy through May 2029. The development
desktop is Linux Mint 22.2, whose Ubuntu base is Noble; Mint itself is not a
separate ROS Tier 1 target. Radxa publishes Noble images for the Q6A. Confirm
the board's actual installed OS before installing packages there.

- [ROS Jazzy platform support](https://www.openrobotics.org/blog/2024/5/ros-jazzy-jalisco-released)
- [Official installation instructions](https://docs.ros.org/en/jazzy/Installation/Ubuntu-Install-Debs.html)
- [Q6A system images](https://docs.radxa.com/en/dragon/q6a/download)

Use the same application source and interface definitions on both hosts. Install
dependencies and build separately for each architecture; do not copy desktop
binaries, Python virtual environments, or colcon build/install output to ARM64.

## Ownership and portability requirements

These are implementation requirements for the forthcoming ROS integration,
not claims that the services below are already implemented.

| Responsibility | Desktop development | Onboard deployment |
| --- | --- | --- |
| Servo output, local trajectory timing, calibration and faults | P4 firmware | P4 firmware |
| Future fast IMU stabilization | P4 firmware | P4 firmware |
| Gateway, one motion arbiter, gait supervision and perception | Desktop | Q6A |
| YOLO inference | Desktop backend | Q6A backend |
| Larger-model reasoning | Local or configured remote service | Desktop or configured remote service |

Keep control and perception logic independent of hostname, repository location,
network address, camera device path, and accelerator vendor. Supply these through
launch parameters or host configuration. Keep robot geometry/calibration separate
from host configuration: changing computers does not change the robot.

Use timestamped, documented ROS messages for observations and semantic movement
requests. Keep measured state distinct from commanded/model-predicted state.
Every host must use consistent units, coordinate frames, and message versions.
Cross-host sensor fusion also needs a defined clock relationship and measured
latency; moving nodes across machines is not timing-neutral.

Maintain one movement authority per robot. Move the gateway and local control
supervisor together when migrating to Q6A. The current gateway's `/environment`
endpoint is intentionally loopback-only; a remote LLM service should provide
reasoning responses to the local supervisor, not take over that endpoint or send
raw servo commands. Network loss to the reasoning server must not replay stale
commands or interrupt an otherwise valid, already-authorized local task. Loss of
the P4 control connection retains its existing firmware fault behavior.

Separate inference from its backend. A CPU backend provides a portable baseline;
desktop CUDA and Q6A acceleration are optional implementations of the same
input/output contract. Exported model formats such as ONNX help portability, but
vendor-compiled engines and quantized models require target-specific validation.
Neither Q6A acceleration nor equal inference performance is established by this
desktop setup. Keep model assets, recordings, logs, and credentials outside
tracked source.

## Install the tools

Enable the official ROS repository using its `ros2-apt-source` package, as
described in the upstream installation instructions. For Ubuntu derivatives,
select `UBUNTU_CODENAME` (`noble` on this desktop), not Mint's `zara` codename.
The repository package used for this setup is `1.3.0~noble` from the
[official 1.3.0 release](https://github.com/ros-infrastructure/ros-apt-source/releases/tag/1.3.0).

With that repository enabled:

```sh
sudo apt-get update
sudo apt-get install --no-remove --no-install-recommends \
  ros-jazzy-ros-base ros-jazzy-rviz2 \
  ros-jazzy-demo-nodes-cpp ros-jazzy-demo-nodes-py \
  python3-colcon-common-extensions python3-rosdep
```

This supplies ROS command-line tools, messaging, transforms, rosbag recording,
RViz, C++/Python demos, and package build/dependency tools. It avoids the broader
desktop metapackage. A headless Q6A deployment can omit RViz and demos and add the
dependencies declared by the actual application packages. No CUDA requirement
belongs in the common ROS dependency set.

Initialize rosdep once per host, then update its cache as the ordinary user:

```sh
sudo rosdep init
rosdep update --rosdistro jazzy
```

If rosdep is already initialized, retain its existing source configuration.
When later resolving application dependencies on Mint, use
`--os=ubuntu:noble` with `rosdep install`; do not edit `/etc/os-release`.

Activate ROS explicitly in each development terminal:

```sh
source /opt/ros/jazzy/setup.bash
```

Use the system-compatible Python interpreter for ROS packages. Keep unrelated
application virtual environments and machine-specific inference dependencies
separate. No global shell startup changes are required.

On this desktop, CMake initially selected an existing local Python 3.10 instead
of Noble's system Python 3.12, which could not import the apt-installed
`catkin_pkg` module. Explicitly select the system interpreter when building:

```sh
colcon build --cmake-args -DPython3_EXECUTABLE=/usr/bin/python3
```

If a previous build cached a different interpreter, add `--cmake-clean-cache`
once. The temporary validation build passed with this setting; no existing
Python installations were replaced.

## Local communication check

In both test terminals, after sourcing ROS, use:

```sh
export ROS_DOMAIN_ID=67
export ROS_AUTOMATIC_DISCOVERY_RANGE=LOCALHOST
```

Domain 67 is a test setting, not a fixed robot identity. Localhost discovery
keeps this check on one machine; it is not an authentication mechanism. A later
multi-machine deployment needs deliberate discovery/network configuration.

Run the C++ publisher in one terminal:

```sh
ros2 run demo_nodes_cpp talker
```

Run the Python subscriber in the other:

```sh
ros2 run demo_nodes_py listener
```

Matching messages confirm communication between the two language runtimes.
Stop both with Ctrl+C. RViz can be started with `rviz2`; successful topic exchange
alone does not prove graphics, GPU inference, robot connectivity, or physical
motion. Do not launch the physical gateway or issue robot commands as part of
this environment check.

## Desktop validation record

Validated on 2026-09-29:

- Installed the six requested ROS/development packages and initialized rosdep;
  the Jazzy dependency index is cached under the ordinary user's `.ros` directory.
- C++ talker and Python listener exchanged nine matching messages with localhost
  discovery and domain 67. MCAP recording captured nine messages and its metadata
  was readable with `ros2 bag info`.
- A temporary `ament_cmake` C++ example built successfully with colcon and the
  explicit system-Python setting above. Source/build/install output stayed in
  `/tmp`, outside the application source tree.
- The restricted agent sandbox denied network-interface discovery, so the
  communication check was repeated successfully with host network access.
- Rosdep reported all dependencies satisfied for the temporary package, and
  `dpkg --audit` reported no incomplete package configuration.
- RViz started, initialized OpenGL 4.6, remained running for the check, and was
  closed afterward. This verifies graphics startup, not an Ainekio model display.

This establishes the desktop toolchain and local ROS communication. No Ainekio
ROS adapter, YOLO service, IMU driver, or Q6A runtime was implemented by this
setup. Firmware and the live gateway were not changed or started by this work;
no robot movement was requested.

During the package-index refresh, the pre-existing GitHub CLI repository reported
a missing signing key. The ROS and Ubuntu indexes refreshed successfully and
the ROS installation completed. No unrelated repository keys were changed.

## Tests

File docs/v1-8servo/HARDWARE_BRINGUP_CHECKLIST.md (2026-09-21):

# Ainekio V1 Hardware Bring-Up Checklist

Scope: the eight-servo V1 body and its Freenove ESP32-S3 controller. These
records retain their original evidence dates. See [Robot Models](../ROBOT_MODELS.md)
for V1/V2 ownership and the separate V2 hardware record.

This document records the intended power topology and the steps for verifying
the assembled robot before normal motion is accepted. It also records the
software media gates that must pass before physical camera and audio results are
attributed to hardware. It is an execution checklist and evidence record;
`Ainekio - System Specification v1.0.docx` remains the behavior and safety
authority, the externally maintained
[Parts Overview](https://docs.google.com/document/d/1wz0kyqttPK3HHL0P0_9lLtRW_B87U5u4kEt-UhttHFA/edit?usp=sharing)
remains the electrical-parts authority, and
[`PINOUT_DIAGNOSTICS.md`](PINOUT_DIAGNOSTICS.md) records the current flashed
board map and diagnostic values.

The Parts Overview has been reviewed for firmware preparation. Its values below
remain planned values until delivered markings, wiring, measurements, and
photographs confirm them. The controller, OV3660 camera, and eight remapped PWM
allocations now have USB-only evidence; the external power system, physical
servo signals and joints, and attached peripherals remain open physical gates.

The companion MetaHuman OS plan is `docs/implementation-plans/VISION_MODEL_IMPLEMENTATION.md` in the MetaHuman repository. MetaHuman owns provider-neutral image-model routing. Ainekio owns real and virtual capture, bounded JPEG and PCM transport, utterance handling, speaker delivery, and hardware safety. Neither program should import the other's private implementation.

## Owner-confirmed power topology

- MusRock MINI560 PRO buck converter #1 supplies the soldered 5 V servo rail.
- A separate MusRock MINI560 PRO buck converter #2 supplies the Freenove board's 5 V input and the MAX98357A amplifier.
- ESP32-S3 GPIO outputs connect directly to the servo signal inputs and provide 3.3 V control signals.
- The board's regulated 3.3 V output supplies the INMP441, SSD1306 OLED, and other 3.3 V systems; the built-in camera is already part of the board.
- Both buck converters, the battery, microcontroller, servos, amplifier, and 3.3 V devices share a common ground.
- Servo load current travels through the dedicated soldered power rail, not through the microcontroller's 5 V or 3.3 V regulator paths.

The topology above is clear. The checks below do not question it. They establish that the particular buck converter, wiring, connectors, regulator, and power source remain within their ratings when the assembled robot is operating. They also establish values that cannot be obtained from a 5 V output label alone, such as loaded voltage drop and the upstream battery-to-ADC measurement ratio.

## Parts and installed-evidence record

These planning values come from the Parts Overview. Replace or confirm them from delivered labels and manufacturer specifications before applying power.

| Item | Installed value | Source or evidence |
| --- | --- | --- |
| Controller board and PCB revision | Freenove ESP32-S3-WROOM CAM delivered; PCB revision not yet recorded | Delivered board; H2 photo required |
| ESP32-S3 module, flash, and PSRAM | ESP32-S3-WROOM-1 N16R8; 16 MB quad flash + 8 MB octal PSRAM | Parts Overview; module-marking photo required |
| Camera sensor/module | Built-in OV3660 | Delivered module marking and successful firmware identification |
| INMP441 microphone module and L/R strap | INMP441; L/R strap not yet selected/observed | Parts Overview; F inspection required |
| MAX98357A amplifier board and supply voltage | MAX98357A at 5 V from electronics buck | Parts Overview; F inspection required |
| MAX98357A gain/channel/shutdown configuration |  |  |
| Speaker | 8 ohm, 2 W | Owner-confirmed |
| Amplifier local bypass/bulk capacitance |  |  |
| 5 V buck converter make/model | Two MusRock MINI560 PRO 5 A modules; one servo, one electronics | Parts Overview; delivered markings required |
| Buck input-voltage range | Pending manufacturer/delivered-part verification | B evidence required |
| Buck continuous and peak current ratings | Advertised 5 A; actual continuous/thermal capability pending load test | B evidence required |
| Power source/battery chemistry and cell count | Sea Jump 2S 7.4 V Li-ion battery, 1000 mAh; hardware protection unverified | Owner-identified delivered battery; manufacturer evidence required |
| Source nominal, full, and minimum safe voltage | 7.4 V nominal, 8.4 V full; minimum governed by battery hardware protection, whose cutoff behavior is not yet verified | Owner policy; H5/H9 evidence required |
| Servo make/model and quantity | Eight MG90S | Parts Overview; delivered labels required |
| Servo specified operating-voltage range |  |  |
| Servo no-load, moving, and stall current |  |  |
| Servo rail wire gauge | 22 AWG; battery feed 20 AWG; signals 30 AWG | Parts Overview; A inspection required |
| Connector, switch, and fuse ratings | KCD1 switch planned; connector and fuse ratings pending confirmation | Parts Overview; A inspection required |
| OLED size, controller, and I2C address | 0.96-inch SSD1306 I2C; address `0x3C` planned, physical scan required | Parts Overview; D evidence required |
| Battery-sense ADC pin | GPIO3 / ADC1 channel 2 | System specification 6.3 and Parts Overview |
| Battery-sense upper/lower resistor values | 100 kOhm upper / 47 kOhm lower with 0.1 uF filter | Parts Overview; installed values must be measured |
| Calculated battery-divider factor | `(100 + 47) / 47 = 3.127659...`; firmware stages `3.12766` | Parts Overview; H9 calibration required |

Do not infer the battery-divider factor from the buck converter's 5 V output. A regulated buck output normally stays near 5 V while its input battery voltage changes. Battery state therefore must be measured upstream of the buck with a documented, ADC-safe divider or with another identified battery-monitor circuit.

## Test equipment

- Current-limited bench supply or a fused power source
- Digital multimeter
- USB/UART connection for boot logs
- Oscilloscope or logic analyzer if available, especially for rail droop and servo pulses
- Manufacturer specifications for the board, buck converter, servos, and battery

Start with the servo plugs disconnected and the robot supported so no joint can bear weight or strike anything.

## Firmware preparation record - 2026-07-15

This dated record prepared the original installable image. The later USB-only
board evidence is recorded under the MAP_B remap and Results sections; it does
not close the remaining assembled-hardware gates.

- [x] Re-read System Specification v1.0 sections 6.2-6.7, H2/H3, and the risk register before changing the map.
- [x] Preserve the required SD_MMC bus. No servo was moved to GPIO38/39/40 and SD was not removed.
- [x] Consolidate the Freenove N16R8 module facts, camera pins, accessory pins, and eight servo pins in `components/ainekio_platform/include/ainekio/platform/pin_map.h`.
- [x] Add software validation for duplicate active GPIOs, invalid input/output use, SD conflicts, N16R8 PSRAM-reserved GPIO33-37, logical joint order, and MCPWM resource collisions.
- [x] Configure 16 MB DIO flash at 80 MHz and 8 MB octal PSRAM at 80 MHz with the startup memory test enabled.
- [x] Pin `espressif/esp32-camera` 2.1.7 and integrate an OV3660 camera task using Freenove's GPIO map, 10 MHz XCLK, JPEG, one XGA-sized PSRAM framebuffer, fresh 1024x768 snapshots, bounded QVGA/VGA preview, a two-frame drop-oldest transmit queue, and protocol counters.
- [x] Configure the planned GPIO3 100 kOhm/47 kOhm divider factor `3.12766` and enable battery monitoring; H9 still compares reported voltage with a multimeter and refines the ADC correction if required.
- [x] Keep the owner-directed all-servo motion profile independent of battery-monitor readings. As of 2026-08-03, battery voltage cannot engage the firmware power guard.
- [x] Retain 16-sample sets every 5 seconds and the 7.0 V low, 6.8 V critical, 7.2 V recovered, and 0.25 V disconnected classifications for telemetry and OLED warnings only. These classifications do not detach motion, cancel audio, close the gateway, or enter deep sleep.
- [x] Retain all eight MCPWM channels and the staggered-center implementation behind the physical-motion build gate.
- [x] Apply an initial 25 percent platform motion range around logical center (`67.5`-`112.5` degrees; `1250`-`1750` us with default calibration) and a 100 ms minimum motion-frame duration to normal semantic motions and calibration commands.
- [x] Preserve explicit `stop`/failsafe detachment of all eight signal GPIOs. This affects the 3.3 V PWM signals only; the external 5 V servo rail is not software-switched.
- [x] Add boot reporting for board profile, PSRAM size, camera readiness, battery-monitor state, and the physical-motion build gate; dump remapped GPIO47/48 configuration for H2 evidence.
- [x] Pass all 11 portable C tests after enabling battery monitoring, including battery thresholds and the calibration-motion gate.
- [x] Re-run the complete A1-A30 emulator/protocol acceptance suite after enabling the all-servo profile; all 30 cases pass.
- [x] Cross-build with ESP-IDF 5.5.4 and battery monitoring enabled. Padded image size is `0x119c20` bytes (1,154,080 bytes), leaving 63 percent of a 3 MiB OTA slot free; DIRAM use is 230,875 bytes (67.55 percent).

### MAP_B board-only remap for H2/H3 - 2026-07-21

| Function | GPIO |
| --- | --- |
| Camera | 4-13 and 15-18, using Freenove's exact signal order in `pin_map.h` |
| Servos R1, R2, L1, L2, R4, R3, L3, L4 | 1, 2, 14, 21, 47, 48, 45, 46 |
| Battery ADC | 3 |
| I2S mic DIN, amp DOUT, BCLK, WS | 19, 20, 41, 42 |
| OLED SDA, SCL | 0, 43 after startup |
| CH343 UART TX, RX | 43, 44 during ROM/boot; GPIO43 hands off to OLED SCL |
| SD_MMC CMD, CLK, DAT0 | 38, 39, 40 |
| BOOT | 0 at reset and as the held-button input; GPIO0 hands off to OLED SDA |

Delivered-hardware H2 rejected GPIO33/34: initializing MCPWM on those N16R8 octal-PSRAM signals immediately corrupted memory. The board-only remap preserves the six valid servo outputs and moves only R4/R3 to exposed GPIO47/48. The OLED moves to GPIO0/43. Its open-drain SDA configuration preserves GPIO0's normal high boot strap and allows a continuous five-second BOOT-button hold to remain distinguishable from short I2C transitions. GPIO43 provides boot-time UART output and is handed to I2C when the display starts. If no OLED responds, the failed I2C bus is released and GPIO43 returns to UART so later faults remain visible. The full-feature image enables all eight remapped PWM channels under the reduced-range safety profile; physical servo movement remains unverified until the signal leads and external 5 V rail are connected.

GPIO0/3/45/46 remain H3 strapping tests. GPIO19/20 intentionally sacrifice native USB for I2S after bring-up. Runtime CH343 transmit logging is unavailable after a responding OLED takes GPIO43; ROM/bootloader UART remains available before that handoff, and an absent OLED now restores the UART. GPIO48 is also wired to the board's WS2812 input, so the onboard RGB LED is unavailable and H2 must confirm that the attached LED input does not disturb its servo signal. SD CMD and DAT0 pull-ups remain an H2 schematic/physical check.

### Still requires physical assembly or recorded evidence

- [ ] H1 reference blink, Wi-Fi, and Freenove camera example.
- [ ] H2 GPIO0/43 handoff, GPIO47/48 PWM initialization, module photo, pull-up review, and concurrent soak.
- [ ] H3 boot-strapping matrix with the divider and all servo signal leads attached.
- [ ] H9 installed-divider and ADC calibration against a multimeter.
- [x] OV3660 identification and repeated boot-time camera initialization.
- [ ] Verify the enabled remapped centered/reduced-range signals and physical outputs on delivered hardware before increasing range above 25 percent.

## Foundation 0: prove media contracts without physical hardware

Close this software gate before using physical camera, microphone, or speaker results to diagnose the end-to-end system.

### Virtual vision

- [ ] Add a deterministic, valid JPEG fixture no larger than 120 KiB with a stable visual marker such as `AINEKIO-7` and a prominent color.
- [ ] Prove `snap` produces a protocol-v1 camera JPEG frame, the gateway converts it into a generic Environment Bridge visual observation, and MetaHuman sends it to a captured or fake image-model endpoint.
- [ ] Prove the same known image produces the expected marker/color answer from the configured real image model.
- [ ] Add a Sesame renderer snapshot producer to the browser shim or a bounded browser-capture adapter and use it as a `CameraSource`.
- [ ] Prove a post-action snapshot reflects a visible simulator scene change.
- [ ] Keep continuous video out of the cognition loop; use explicit or low-rate bounded JPEG snapshots first.

### Virtual hearing and speaking

- [x] Build a microphone fixture from multiple 640-byte, 16 kHz mono PCM frames with silence, speech-like energy, and explicit VAD open/close boundaries.
- [x] Buffer a bounded utterance before transcription. Do not invoke speech recognition independently for every 20 ms PCM frame.
- [x] Install the configured transcription path in production gateway startup and prove one utterance becomes one generic Environment Bridge text observation.
- [ ] Define the generic outbound speech-delivery contract separately from `sendText`; conversational text acknowledgement alone does not play the robot speaker.
- [ ] Route synthesized 16 kHz mono PCM through `GatewayService.tts_speak`, preserving start, frame, end, cancellation, and completion order.
- [ ] Use a recording or fixture speaker sink to prove the outbound PCM stream without ALSA or physical hardware.
- [ ] Prove camera frames, microphone frames, and speaker frames retain their bandwidth priority and drop/counter behavior under combined virtual load.

**Pass:** A known virtual image reaches the image model, a bounded virtual utterance reaches MetaHuman as text, and a bounded MetaHuman speech response reaches a recording speaker sink. No physical device, Linux webcam, or ALSA device is required for this pass.

**Hearing evidence (2026-07-17):** Focused gateway and bridge tests prove VAD
grouping, missing-frame silence, bounded duration, WAV validation, one Whisper
call, and one metadata-bearing text observation. A live 2.1-second, 16 kHz mono
PCM fixture passed through the Ainekio binary-envelope parser and MetaHuman's
running `base.en` Whisper server. Whisper returned `Inekio hears this test
phrase.` The full Foundation 0 pass remains open because virtual vision and
outbound speech delivery are separate unfinished gates.

### Local microWakeWord implementation

- [x] Add the authenticated protocol-v1 `wake` command with persistent `enabled` and trained-model `model` fields.
- [x] Store the robot-owned setting in the existing NVS preferences namespace as optional `wake_enabled` and `wake_model` keys.
- [x] Default a first boot or missing-key migration to `enabled=false` and `model=ainekio` without erasing profile, ADC calibration, servo calibration, poses, Wi-Fi, or identity settings.
- [x] Report `wake_enabled`, `wake_model`, and `wake_ready` in firmware and emulator status.
- [x] Add gateway API and dashboard controls for the setting, plus protocol, emulator, gateway, and dashboard coverage.
- [x] Keep `wake_ready=false` and reject both wake enablement and `mic` with `gate=wake` while no trained model is installed. The fixed energy detector is not presented as wake-word detection.
- [x] Select the open microWakeWord quantized TFLite format instead of attempting to reverse engineer proprietary WakeNet weights. Pin TensorFlow Lite Micro 1.3.7, ESP-NN 1.1.2, and the micro-speech frontend 1.2.3.
- [x] Integrate on-device 16 kHz streaming feature generation and TFLite Micro inference. Wake mode keeps PCM local until a real model detection, emits the wake event once, and forwards the following bounded utterance through the existing VAD boundary protocol.
- [x] Add the bounded `ainekio-microwakeword-v1` installed-model manifest, SHA-256 verification, TFLite/tensor/operator validation, provenance fields, and a tested local packaging tool.
- [x] Document an entirely local training, packaging, and LittleFS loading workflow in `docs/LOCAL_WAKE_WORD.md`. Voice data, generated features, checkpoints, and weights stay on owner-controlled hardware.
- [ ] Freeze the intended pronunciation of “Ainekio,” then locally train, license, version, and evaluate the actual quantized model. Do not mark it ready based on synthetic training accuracy alone.
- [ ] Install the locally trained package and measure RAM, PSRAM, flash, CPU, false accepts, false rejects, camera, Wi-Fi, servo, speaker, and audio coexistence on the N16R8 board.
- [ ] Extend robot status with an installed-model list so the gateway model selector is populated from the robot rather than a hard-coded option.
- [ ] Define and prove an authenticated, checksummed or signed model-package install/activation/rollback path. Switching an installed model should not require application reflashing; a new phrase still requires a trained model artifact.
- [x] Add bounded pre-roll, a 15-second firmware and gateway maximum, Espressif `vadnet1_medium` post-wake endpointing, gateway utterance assembly, speaker-time microphone muting, cooldown, and a 2.56-second PSRAM microphone transport queue. Keep the custom `Ainekio` microWakeWord model and do not enable WakeNet, AEC, or command recognition.
- [ ] Measure VADNet RAM, PSRAM, CPU, model-load time, microphone drops, and audio-task stack margin on the physical N16R8 controller. Calibrate the 100 ms pre-roll, one-second minimum, one-second VAD silence window, VAD mode, 15-second maximum, and 800 ms post-speaker cooldown using quiet, fan, music, and normal-speech trials.

**Current result:** The durable control plane and real microWakeWord inference engine are implemented and cross-build. No `Ainekio` weights are installed, so the checked-in image intentionally remains `wake_ready=false` and first boot remains disabled. The gateway is a controller and display surface, not the source of truth.

## A. Unpowered wiring inspection

- [ ] Photograph the finished power and signal wiring clearly enough to trace it later.
- [ ] Verify supply polarity at each buck input and each 5 V output.
- [ ] Verify that the servo rail receives regulated 5 V, not raw battery voltage.
- [ ] Verify that the controller receives 5 V only at its documented 5 V input.
- [ ] Verify that 3.3 V devices receive power only from the board's 3.3 V output.
- [ ] Verify continuity between supply ground, controller ground, servo ground, and peripheral ground.
- [ ] Verify that servo power does not pass through the board regulator or narrow controller traces.
- [ ] Verify that no 5 V line connects to an ESP32 GPIO.
- [ ] Check for shorts between 5 V and ground and between 3.3 V and ground.
- [ ] Check wire, connector, switch, and fuse ratings against the expected combined current.

**Pass:** The wiring matches the topology above, polarity is correct, grounds are common, and no short or over-rated current path is found.

## B. Verify each buck converter by itself

- [ ] Test the servo buck and electronics buck separately with the controller, servos, and peripherals disconnected.
- [ ] Set a conservative current limit on the test supply.
- [ ] Apply the lowest expected source voltage and measure the buck output.
- [ ] Adjust or confirm the output at the intended 5 V setting.
- [ ] Repeat at nominal and maximum source voltage.
- [ ] Add a controlled load within the converter's rating and record output voltage, input current, output current, ripple if measurable, and temperature.
- [ ] Remove input power and verify there is no harmful backfeed from USB or another connected source.

**Pass:** Output remains within the documented voltage limits of every connected 5 V device throughout the intended input and load range, with no shutdown or excessive heating.

## C. Power the controller only

- [ ] Leave every servo disconnected.
- [ ] Apply 5 V to the board's documented 5 V input.
- [ ] Measure the 5 V input and regulated 3.3 V rail at the board.
- [ ] Capture the complete boot log.
- [ ] Confirm the exact ESP32-S3 module, flash size, and PSRAM size reported at boot.
- [ ] Confirm there are no brownout resets, boot loops, regulator overheating, or unexpected current draw.
- [ ] Check whether USB connection changes or backfeeds either power rail.

**Pass:** The board boots repeatedly, reports the expected hardware, and both rails remain within the connected parts' specified limits.

## D. Verify the OLED

- [ ] Connect only the SSD1306 OLED to the documented I2C power and pins.
- [ ] Confirm whether its address is `0x3C` or `0x3D`.
- [ ] Confirm the display initializes without blocking the rest of the firmware if it is absent or faulty.
- [ ] Confirm the setup network, stable eight-character key, and
  `192.168.4.1` setup address are legible on the physical display.
- [ ] Join `Ainekio-Setup` with that key and confirm the configuration form opens
  directly at `http://192.168.4.1/` without a second login prompt.
- [ ] While AP+STA mode is active, confirm the same setup HTTP service rejects a
  request arriving through the normal station interface.
- [ ] Reboot twice and confirm the device setup key remains unchanged; a full
  NVS erase is the only service operation that should replace it.
- [ ] After setup, confirm the joined SSID, DHCP address, and gateway state are
  legible and accurate.
- [ ] Exercise all 37 named expressions and all 48 encoded face frames, checking alignment, corruption, and transitions.
- [ ] Measure the 3.3 V rail during display updates.

**Pass:** Text and faces fit the physical display, all intended frames render, and display activity does not destabilize the 3.3 V rail.

## E. Verify the built-in camera

- [ ] Confirm the exact Freenove board revision and camera sensor from its markings or documentation.
- [ ] Confirm the board's camera pin map rather than assuming a generic ESP32-S3-CAM layout.
- [ ] Confirm PSRAM is detected and enabled.
- [ ] Run the matching Freenove or Espressif camera example before testing the Ainekio camera path.
- [ ] Capture a still JPEG at a conservative frame size such as QVGA or VGA.
- [ ] Record image size, capture time, stability, and 5 V/3.3 V rail measurements.
- [ ] After the reference example passes, test the Ainekio snapshot command.
- [ ] Test streaming only after still capture is reliable.

**Pass:** The reference camera test and Ainekio still capture work repeatedly without resets, corrupted frames, or unacceptable rail droop.
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

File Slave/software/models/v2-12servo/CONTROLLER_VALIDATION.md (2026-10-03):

# Centered motion revision, 2026-10-02

The current source uses the screw-aware coupled linkage region and separate
mounting references: shoulder1650 µs, carrier856 µs, crank723 µs at the retained
CAD mounting marks. The conversion remains provisional; existing device NVS
calibration is preserved. There is no new runtime collision limiter.

Full steady Walk sweep is97.7 mm and forward Run sweep104 mm. Walk↔Run uses a
continuous eight-cycle morph. Landing prediction includes the changing future
contact duration, and rephasing swing paths follow the body while retaining
committed touchdown targets and planted anchors. Normal stride changes also
respect committed contacts. No automatic all-feet pause is inserted.

Current validation covers28 model/core tests and9 firmware/IMU host tests, all
passing. It includes4,155,048 sampled leg-pose checks for threshold/stride/rate
changes and435,945 interpolation breakpoint checks on long transitions. The23
finite motions pass124,124 authored joint poses and conservative interpolation
proof against the internal linkage region. All16 native locomotion recordings
pass159,104 leg poses, along with FK, sole and closure checks.

The final Run recording contains4024 samples. A separate actual-mesh BVH check
found no intersections in148 selected robot poses /592 leg poses, including
critical interpolation midpoints, all four captured leg assemblies and the
modeled4 mm×1.5 mm shaft screw heads. This is sampled internal-linkage evidence,
not complete-body, cable, loaded-servo or physical running qualification.

Upright now retains four-foot support while leveling and shifting rearward,
then withdraws the front pair after the modeled COM reaches the rear support.
Minimum provisional support margin after its Sit prefix is1.563 mm. Other
expressive motions retain existing support/floor limitations; mass distribution
and dynamic balance are unmeasured.

Source/build validation does not flash firmware, write calibration or command
the physical robot. Blender preview parity is a separate check. The dated
sections below are historical and describe earlier source/deployments.

# Compact controller validation

The preceding controller replacement was built and application-flashed as `0.7.0-p4-compact-motion`.
The measurements below distinguish compiled resources, desktop geometry and
hardware observations under the operating conditions stated in each section.

## Saved named-motion speed, 2026-09-25

Body Control provides one shared **Motion speed (×)** for Stand, Sit and finite
named gestures, defaulting to 2×. The input accepts arbitrary positive numeric
multipliers without an application-imposed minimum, maximum or fixed increment.
Editing affects the next named motion; Save on robot retains the value across
restarts, and Read from robot confirms the stored value. Saving stops outputs
through the existing owner; starting a subsequent motion resumes operation.

A single-precision multiplier directly scales the existing entry and clip clocks.
The unrequested 0.25–3× checks, integer thousandths conversion and unused twelve-
joint derivative-rescaling loop were removed. There is one rate representation
from command decoding through playback and the separate four-byte `motion_rate`
NVS record. Missing/unreadable settings use the 2× default. Only numeric validity
is checked for the multiplier; no new motion/output restrictions were introduced.
No new queue, motion assets, runtime module, allocation or servo-loop storage
write was added. Calibration, motion paths, V1, startup Home and gait controls
retain their existing behavior.

Matched ESP-IDF 5.5.4 builds with unchanged SDK configuration:

| Resource | Before feature | Final | Change |
| --- | ---: | ---: | ---: |
| Application binary | 2,369,408 B | 2,370,848 B | +1,440 B |
| Flash code | 1,322,926 B | 1,324,126 B | +1,200 B |
| Flash read-only data | 931,000 B | 931,176 B | +176 B |
| Static RAM data + BSS | 39,260 B | 39,324 B | +64 B |
| Total occupied internal RAM, including code | 138,494 B | 138,558 B | +64 B |

The final image is 400 bytes smaller than the initial capped implementation;
static RAM is unchanged from it. The existing depth-one body request queue adds
8 bytes of payload versus the pre-feature firmware. No additional queue exists.

All 30 native/desktop tests pass with Release assertions enabled and no skips.
Production-controller tests cover every one of the 23 clips at 0.25×, 1×, 2×,
3×, 4×, 6×, 8× and 12×: equal choreography-time pulse outputs, scaled entry,
completion and unaffected gait timing. Config tests cover a saved value above
3×, reload, failed writes, invalid records and unchanged joint calibration.
Gateway/dashboard tests pass (27), variable-walk tests pass (42), and JavaScript
race tests pass. Isolated Chrome tests verify uncapped 6.125× entry, command,
save and readback after an actual reload, plus mobile layout and calibration UX.

Application SHA-256: `50a9092e3cde37a7c2644820f6e5082e2b5de29be79cac8f89b556fca0e9eaed`.
ELF SHA-256: `47a4d6aa94a5be7aedd90637427b9a0fd590570b3542505b4ba699963dbe3288`.

The application was flashed to the verified active `ota_0` slot at `0x20000`.
Flash digest verification passed. The first 128 KiB were byte-for-byte unchanged,
preserving bootloader, partition table, NVS, PHY and OTA selection metadata;
protected-region SHA-256: `e9b9e7fd47cc172bdc46f3a87efbc7df82c089e31a5fb49d88b7a8d947726810`.
The gateway was restarted with its existing credentials and runtime data.
The robot's pre-update speed (3×) was read and saved in the new
float representation by the deployment tool, without a firmware migration path.
All twelve saved joint mappings and inversion settings matched after flashing.
A further reboot retained the 3× setting with `saved:true` and
all twelve joint mappings unchanged. Both boots reported the matching ELF prefix.

Hardware deployment checks cover startup Home and settings operations, not
loaded high-speed gestures. Servo tracking and worst-case P4 frame timing at
higher multipliers have not been measured. Raw NVS, calibration snapshots,
credentials and boot logs are excluded from the repository.

## Gait leverage revision, 2026-09-25

The approved Walk body reference is -8 mm, 6 mm below its preceding trajectory.
The 92 mm stride, 30 mm rearward bias, 14 mm lift, sway and cadence are retained.
Named Stand and all 23 compiled gestures retain their existing poses and timing.
Calibration, electrical mapping, assembly references and V1 are unchanged.

Forward Run keeps its 104 mm maximum sweep, paired contacts and separated lanes;
body reference changes -6 to -9 mm, nose-up bias 6 to 3 degrees, and maximum lift
22 to 18 mm. Backward Run/turn body reference changes -2 to -8 mm. Those coordinated
changes preserve reach during rapid Walk/Run changes without extra solver passes.
Crab changes -18 to -22 mm and establishes its first anchors over two cycles
(three for backward, as before);
steady travel, stance width and cadence are unchanged. Crawl's -35 mm working
height, stride and lift remain; it enters from the revised walking-ready pose.

Thirty Release native/desktop tests pass with assertions enabled and no skips.
The same production body controller covers saved calibration, Home, gait entry,
Finish and return to Walk/Stand. Expanded full-CAD checks exercise all four gait
families and every direction, their own previous outputs, speed changes and Finish
at 20/40 ms. Native envelope tests also cover 10/30 ms, finite commands, rapid
threshold reversals and advanced stride/cadence extremes, including key midpoints.
Both four-bar branch signs are checked. Regression floors are 45 degrees at the
output during planned stance, 35 during swing, 20 at the crank and 3 mm remaining
extension. These are offline regression margins, not measured torque capability.

The original compact sole is unchanged. Walk/Crawl/Run retain their original
0.151 mm support allowance; the refined Crab sole has an explicitly tested extra
0.08 mm height allowance in its revised poses, replacing the prior 0.07 mm value.
Horizontal foot error and below-target rejection remain independently strict.
The compiled gesture and servo data are byte-for-byte identical to the baseline.

Matched ESP-IDF 5.5.4 builds with identical SDK configuration:

| Resource | Before | After | Change |
| --- | ---: | ---: | ---: |
| Application binary | 2,369,264 B | 2,369,408 B | +144 B |
| Flash code | 1,322,798 B | 1,322,926 B | +128 B |
| Flash read-only data | 930,984 B | 931,000 B | +16 B |
| Static RAM data + BSS | 39,260 B | 39,260 B | 0 B |
| Total occupied internal RAM, including code | 138,494 B | 138,494 B | 0 B |

The expanded full-sole command-path check covers 14,391 robot poses; maximum
horizontal foot error is 0.000070 mm. Across that sequence and its joint midpoints,
minimum output angle is 46.61 degrees in planned stance and 37.57 in swing, with
at least 3.13 mm remaining extension. The wider native envelope tests perform
9,611,184 leg checks (including repeated endpoints/midpoints), without branch
reversals. Recorded locomotion midpoint checks retain positive body clearance
and no floor penetration beyond 0.000087 mm numerical error. These are sampled
geometric checks, not a continuous-time collision or load proof.

Runtime changes are gait constants, a separate retained Stand height and the
Crab startup-ramp selection. No new solver, runtime motion table, allocation,
state field, buffer or output owner was added. Existing generated recordings and
reports were replaced in place; the new regression helper is host-only. The
old Walk-height value remains solely as the reviewed Stand/reference height.
All compiled gesture and servo tables are identical to the baseline.

Application SHA-256:
`ec8543b6e2ae8281ea4a97e68d8c348e08e10432248d0bfd6aaef41e6fe1f438`.
The full measurements and source identities are in
[`motions/locomotion/validation.json`](motions/locomotion/validation.json).

The checks above were offline. Loaded torque, slip, balance, actual speed and
whole-robot collision clearance remain unqualified. Current P4 frame timing and
dynamic RAM are not measured; earlier timing results below do not qualify this
revision. The direct geometry solver retains its four-pass bound and buffers.

### Application deployment verified 2026-09-25

The gait leverage revision above is now installed on the connected ESP32-P4
revision 1.3. The exact 2,369,408-byte application identified above was written
to the existing active `ota_0` slot at `0x20000`; flash digest verification passed.
Only the application was written. A before/after readback of `0x00000` through
`0x1ffff` was byte-for-byte identical, covering the bootloader, partition table,
saved NVS calibration, PHY data and OTA selection metadata. Other application
and LittleFS partitions were not written.

The reboot reported the matching ELF SHA-256 prefix `2aa15e298...`; the complete
build ELF SHA-256 is
`2aa15e2987eafa4912016a78f4316d4ba86e804740b804f303ee2c60a5511a70`.
The console confirmed calibration `valid=1 saved=1 dirty=0`; its Home values
were retained. The controller authenticated and output status reported ready,
armed and without a fault. This deployment allowed the normal startup Home sequence but
sent no gait commands. Boot and read-only status checks do not establish loaded
walking performance or new motion/frame timing measurements.

Startup also logged I2S disable-before-enable messages and unavailable removable
storage (`ESP_ERR_TIMEOUT`). An initial gateway connection timeout recovered before
authentication. These peripheral/transport observations were not changed or
qualified by this application deployment.

Preserved-region SHA-256 before and after:
`376036bff27f8cf83a1c58e01323976bcd9719fb80d271b3d74d65cc79e5acd8`.
Structured deployment evidence is recorded in the locomotion validation report;
raw device configuration and serial logs are excluded from the repository.

## Deployment verified 2026-09-24

The reviewed motions, continuous six-direction Crab and fixed-angle turn removal
are now application-flashed to the P4. The firmware version label remains
`0.7.0-p4-compact-motion`; this build is identified by the hashes below.

- Corrected both hello/status command buffers to derive their capacity from the
  actual base-command array. The added Crab declarations otherwise exceeded the
  former allocation by six pointers. A native address/undefined-behavior sanitizer
  check generated and encoded all 39 declarations without an overrun.
- Fresh Release build: 29 native/desktop tests passed, including Crab geometry;
  72 gateway/protocol tests passed with the native command executable and no
  skips. Dashboard motion-race tests passed after updating their select-option
  fixture and adding Crab Start/Finish/feature-negotiation coverage.
- All 23 compiled clips passed 61,919 full-sole comparison samples: maximum
  vertex difference 0.012861 mm and clearance difference 0.007843 mm.
- Application: 2,369,264 bytes; SHA-256
  `50ce294fd03d26fcc2fac66958ade6ea2d0f77bd8ef17c9fbfac927230ba0ae2`.
  The write at active OTA slot `0x20000` passed flash verification. No bootloader,
  partition table, NVS, OTA metadata or stored assets were written. Readbacks of
  `0x8000` through `0x11fff` before/after were byte-for-byte identical.
- Boot confirmed ELF SHA-256
  `94a53eaa8d18952094dc61d558adb3da9229f0219a3617bd1b642c4d832cde5d`,
  controller authentication, and the new catalog. Calibration reported valid,
  saved and clean, with carrier Home pulses 1270 and 1230 us preserved. Outputs
  were explicitly disabled after verification.

This verifies build, flash, boot and connection. It does not qualify loaded
movement or measure the new gait's P4 frame timing. One initial gateway connection
timeout recovered before authentication; the earlier transport limitation remains.
The offline sections below preserve the earlier comparison checkpoints.
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

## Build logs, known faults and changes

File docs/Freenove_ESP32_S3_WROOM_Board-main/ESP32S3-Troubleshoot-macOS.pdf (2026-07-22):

## CH34x Driver Installation on macOS

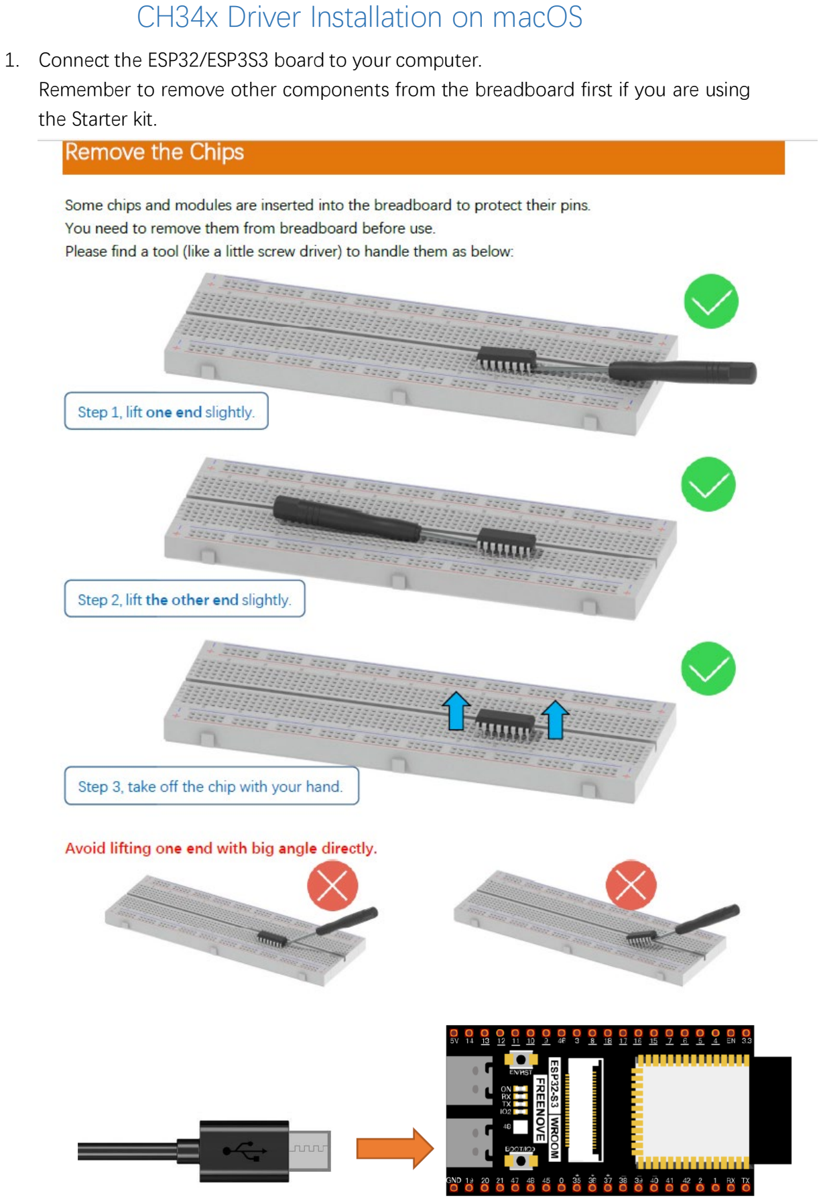
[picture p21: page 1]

1. Connect the ESP32/ESP3S3 board to your computer.
Remember to remove other components from the breadboard first if you are using the Starter kit.

2. Download the ch34x driver from WCH official. https://www.wch-ic.com/downloads/CH34XSER_MAC_ZIP.html
3. Open the CH34xVCPDriver.pkg to install the driver.

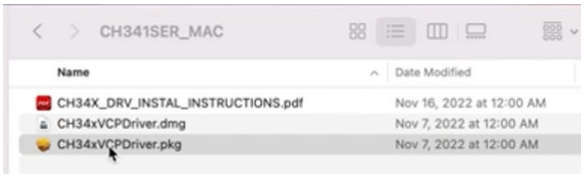
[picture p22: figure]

If it is blocked, please open Security Preferences to allow it.

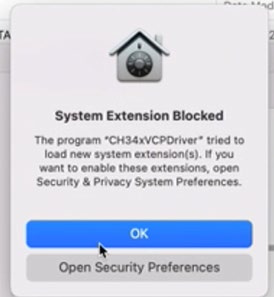
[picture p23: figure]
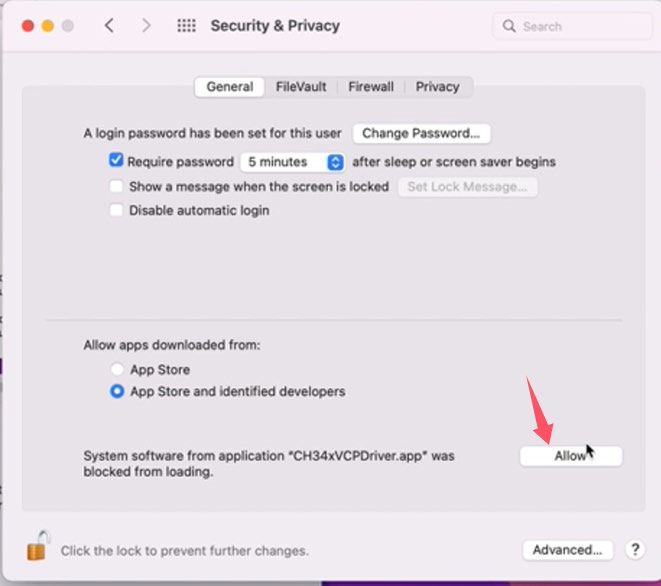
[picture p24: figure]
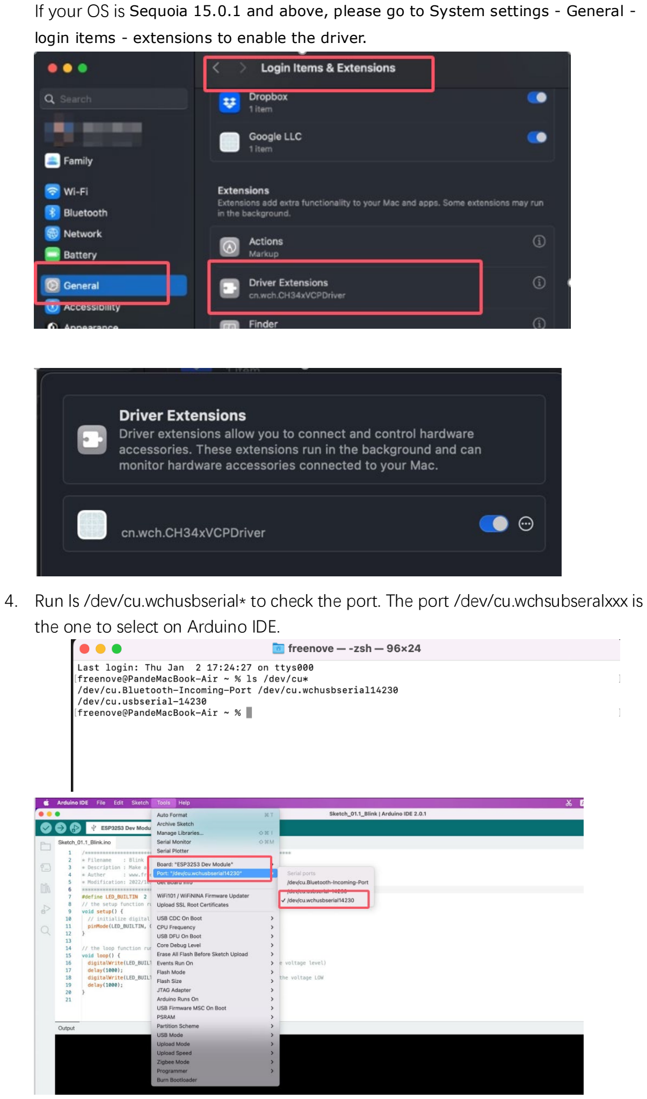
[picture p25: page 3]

If your OS is Sequoia 15.0.1 and above, please go to System settings - General -login items - extensions to enable the driver.

4. Run ls /dev/cu.wchusbserial* to check the port. The port /dev/cu.wchsubseralxxx is the one to select on Arduino IDE.

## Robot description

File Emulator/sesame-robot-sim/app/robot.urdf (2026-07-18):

<?xml version="1.0" ?>
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
<robot name="onshape">
  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
  <link name="internal_frame">
    <inertial>
      <origin xyz="0.000176894 -0.00474991 0.00186732" rpy="0 0 0"/>
      <mass value="0.0625592"/>
      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
    </inertial>
    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
  </link>
  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
  <link name="femur_joint_l2">
    <inertial>
      <origin xyz="-0.00781171 -0.0167497 0.00432361" rpy="0 0 0"/>
      <mass value="0.000680634"/>
      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
    </inertial>
    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
  </link>
  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
  <link name="foot_joint_l4">
    <inertial>
      <origin xyz="-1.5443e-05 -0.00565475 -0.0161842" rpy="0 0 0"/>
      <mass value="0.0139894"/>
      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
    </inertial>
    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
  </link>
  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
  <link name="l4_p1">
    <origin xyz="0 0 0" rpy="0 -0 0"/>
    <inertial>
      <origin xyz="0 0 0" rpy="0 0 0"/>
      <mass value="1e-9"/>
      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
    </inertial>
  </link>
  <joint name="l4_p1_frame" type="fixed">
    <origin xyz="0.001905 -0.04706 -0.019813" rpy="1.5708 1.5708 0"/>
    <parent link="foot_joint_l4"/>
    <child link="l4_p1"/>
    <axis xyz="0 0 0"/>
  </joint>
  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
  <link name="l4_p2">
    <origin xyz="0 0 0" rpy="0 -0 0"/>
    <inertial>
      <origin xyz="0 0 0" rpy="0 0 0"/>
      <mass value="1e-9"/>
      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
    </inertial>
  </link>
  <joint name="l4_p2_frame" type="fixed">
    <origin xyz="0.001905 -0.04706 -0.0120344" rpy="1.5708 1.5708 0"/>
    <parent link="foot_joint_l4"/>
    <child link="l4_p2"/>
    <axis xyz="0 0 0"/>
  </joint>
  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
  <link name="l4_p3">
    <origin xyz="0 0 0" rpy="0 -0 0"/>
    <inertial>
      <origin xyz="0 0 0" rpy="0 0 0"/>
      <mass value="1e-9"/>
      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
    </inertial>
  </link>
  <joint name="l4_p3_frame" type="fixed">
    <origin xyz="-0.00508 -0.04706 -0.019813" rpy="1.5708 1.5708 0"/>
    <parent link="foot_joint_l4"/>
    <child link="l4_p3"/>
    <axis xyz="0 0 0"/>
  </joint>
  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
  <link name="l4_p4">
    <origin xyz="0 0 0" rpy="0 -0 0"/>
    <inertial>
      <origin xyz="0 0 0" rpy="0 0 0"/>
      <mass value="1e-9"/>
      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
    </inertial>
  </link>
  <joint name="l4_p4_frame" type="fixed">
    <origin xyz="-0.00508 -0.04706 -0.0123397" rpy="1.5708 1.5708 0"/>
    <parent link="foot_joint_l4"/>
    <child link="l4_p4"/>
    <axis xyz="0 0 0"/>
  </joint>
  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
  <joint name="l4" type="revolute">
    <origin xyz="-0.0207104 -0.0313751 0.01779" rpy="-1.5708 0 -2.35619"/>
    <parent link="femur_joint_l2"/>
    <child link="foot_joint_l4"/>
    <axis xyz="0 0 1"/>
    <limit effort="10" velocity="10" lower="-3.141592653589793" upper="3.141592653589793"/>
  </joint>
  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
  <joint name="l2" type="revolute">
    <origin xyz="0.0243034 -0.0301724 0.0179057" rpy="-3.14159 0 -3.14159"/>
    <parent link="internal_frame"/>
    <child link="femur_joint_l2"/>
    <axis xyz="0 0 1"/>
    <limit effort="10" velocity="10" lower="-3.141592653589793" upper="3.141592653589793"/>
  </joint>
  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
  <link name="femur_joint_r2">
    <inertial>
      <origin xyz="-0.00784353 0.0167717 0.004359" rpy="0 0 0"/>
      <mass value="0.000678324"/>
      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
    </inertial>
    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
  </link>
  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
  <link name="foot_joint_r4">
    <inertial>
      <origin xyz="-1.59153e-05 0.00565415 -0.0161839" rpy="0 0 0"/>
      <mass value="0.0139878"/>
      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
    </inertial>
    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
  </link>
  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
  <link name="r4_p1">
    <origin xyz="0 0 0" rpy="0 -0 0"/>
    <inertial>
      <origin xyz="0 0 0" rpy="0 0 0"/>
      <mass value="1e-9"/>
      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
    </inertial>
  </link>
  <joint name="r4_p1_frame" type="fixed">
    <origin xyz="0.001905 0.04706 -0.0195906" rpy="-1.5708 1.5708 0"/>
    <parent link="foot_joint_r4"/>
    <child link="r4_p1"/>
    <axis xyz="0 0 0"/>
  </joint>
  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
  <link name="r4_p2">
    <origin xyz="0 0 0" rpy="0 -0 0"/>
    <inertial>
      <origin xyz="0 0 0" rpy="0 0 0"/>
      <mass value="1e-9"/>
      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
    </inertial>
  </link>
  <joint name="r4_p2_frame" type="fixed">
    <origin xyz="0.001905 0.04706 -0.0120344" rpy="-1.5708 1.5708 0"/>
    <parent link="foot_joint_r4"/>
    <child link="r4_p2"/>
    <axis xyz="0 0 0"/>
  </joint>
  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
  <link name="r4_p3">
    <origin xyz="0 0 0" rpy="0 -0 0"/>
    <inertial>
      <origin xyz="0 0 0" rpy="0 0 0"/>
      <mass value="1e-9"/>
      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
    </inertial>
  </link>
  <joint name="r4_p3_frame" type="fixed">
    <origin xyz="-0.00508 0.04706 -0.0192853" rpy="-1.5708 1.5708 0"/>
    <parent link="foot_joint_r4"/>
    <child link="r4_p3"/>
    <axis xyz="0 0 0"/>
  </joint>
  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
  <link name="r4_p4">
    <origin xyz="0 0 0" rpy="0 -0 0"/>
    <inertial>
      <origin xyz="0 0 0" rpy="0 0 0"/>
      <mass value="1e-9"/>
      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
    </inertial>
  </link>
  <joint name="r4_p4_frame" type="fixed">
    <origin xyz="-0.00508 0.04706 -0.0123397" rpy="-1.5708 1.5708 0"/>
    <parent link="foot_joint_r4"/>
    <child link="r4_p4"/>
    <axis xyz="0 0 0"/>
  </joint>
  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
  <joint name="r4" type="revolute">
    <origin xyz="-0.0207104 0.0313751 0.01779" rpy="1.5708 0 2.35619"/>
    <parent link="femur_joint_r2"/>
    <child link="foot_joint_r4"/>
    <axis xyz="0 0 1"/>
    <limit effort="10" velocity="10" lower="-3.141592653589793" upper="3.141592653589793"/>
  </joint>
  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
  <joint name="r2" type="revolute">
    <origin xyz="0.0243034 0.0206276 0.0179057" rpy="3.14159 -0 3.14159"/>
    <parent link="internal_frame"/>
    <child link="femur_joint_r2"/>
    <axis xyz="0 0 1"/>
    <limit effort="10" velocity="10" lower="-3.141592653589793" upper="3.141592653589793"/>
  </joint>
  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
  <link name="femur_joint_l1">
    <inertial>
      <origin xyz="-0.00780689 0.0167431 0.0043184" rpy="0 0 0"/>
      <mass value="0.000680971"/>
      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
    </inertial>
    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
  </link>
  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
  <link name="foot_joint_l3">
    <inertial>
      <origin xyz="-1.71455e-05 0.00566323 -0.0161873" rpy="0 0 0"/>
      <mass value="0.013998"/>
      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
    </inertial>
    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
  </link>
  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
  <link name="l3_p1">
    <origin xyz="0 0 0" rpy="0 -0 0"/>
    <inertial>
      <origin xyz="0 0 0" rpy="0 0 0"/>
      <mass value="1e-9"/>
      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
    </inertial>
  </link>
  <joint name="l3_p1_frame" type="fixed">
    <origin xyz="0.001905 0.0638208 -0.0199857" rpy="-1.5708 1.5708 0"/>
    <parent link="foot_joint_l3"/>
    <child link="l3_p1"/>
    <axis xyz="0 0 0"/>
  </joint>
  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
  <link name="l3_p2">
    <origin xyz="0 0 0" rpy="0 -0 0"/>
    <inertial>
      <origin xyz="0 0 0" rpy="0 0 0"/>
      <mass value="1e-9"/>
      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
    </inertial>
  </link>
  <joint name="l3_p2_frame" type="fixed">
    <origin xyz="0.001905 0.0638208 -0.0120344" rpy="-1.5708 1.5708 0"/>
    <parent link="foot_joint_l3"/>
    <child link="l3_p2"/>
    <axis xyz="0 0 0"/>
  </joint>
  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
  <link name="l3_p3">
    <origin xyz="0 0 0" rpy="0 -0 0"/>
    <inertial>
      <origin xyz="0 0 0" rpy="0 0 0"/>
      <mass value="1e-9"/>
      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
    </inertial>
  </link>
  <joint name="l3_p3_frame" type="fixed">
    <origin xyz="-0.00508 0.0638208 -0.0199857" rpy="-1.5708 1.5708 0"/>
    <parent link="foot_joint_l3"/>
    <child link="l3_p3"/>
    <axis xyz="0 0 0"/>
  </joint>
  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
  <link name="l3_p4">
    <origin xyz="0 0 0" rpy="0 -0 0"/>
    <inertial>
      <origin xyz="0 0 0" rpy="0 0 0"/>
      <mass value="1e-9"/>
      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
    </inertial>
  </link>
  <joint name="l3_p4_frame" type="fixed">
    <origin xyz="-0.00508 0.0638208 -0.0123397" rpy="-1.5708 1.5708 0"/>
    <parent link="foot_joint_l3"/>
    <child link="l3_p4"/>
    <axis xyz="0 0 0"/>
  </joint>
  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
  <joint name="l3" type="revolute">
    <origin xyz="-0.0207104 0.0313751 0.01779" rpy="1.5708 -0 2.35619"/>
    <parent link="femur_joint_l1"/>
    <child link="foot_joint_l3"/>
    <axis xyz="0 0 1"/>
    <limit effort="10" velocity="10" lower="-3.141592653589793" upper="3.141592653589793"/>
  </joint>
  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
  <joint name="l1" type="revolute">
    <origin xyz="-0.0240966 -0.0301724 0.0179057" rpy="-3.14159 0 -0"/>
    <parent link="internal_frame"/>
    <child link="femur_joint_l1"/>
    <axis xyz="0 0 1"/>
    <limit effort="10" velocity="10" lower="-3.141592653589793" upper="3.141592653589793"/>
  </joint>
  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
  <link name="femur_joint_r1">
    <inertial>
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

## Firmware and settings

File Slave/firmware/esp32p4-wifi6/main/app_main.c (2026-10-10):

#include "board.h"
#include "config.h"
#include "controller.h"
#include "network.h"
#include "system.h"
#include "display.h"
#include "ainekio/p4_assets.h"

#include <stdio.h>
#include <string.h>
#include "esp_check.h"
#include "esp_console.h"
#include "esp_system.h"
#include "freertos/FreeRTOS.h"
#include "freertos/task.h"
#include "nvs_flash.h"

static int board_command(int argc, char **argv)
{
    (void)argc; (void)argv;
    ainekio_p4_board_identify();
    const ainekio_pca_status_t s = ainekio_pca_status(ainekio_p4_output());
    printf("output ready=%d armed=%d fault=%d outstanding=%d\n",
           s.ready, s.armed, s.fault, s.in_flight);
    printf("console minimum_free_stack=%u bytes\n", (unsigned)uxTaskGetStackHighWaterMark(NULL));
    return 0;
}

static int disable_command(int argc, char **argv)
{
    (void)argc; (void)argv;
    ainekio_pca_emergency_disable(ainekio_p4_output(), AINEKIO_PCA_FAULT_EMERGENCY);
    puts("Outputs disabled; use home to resume.");
    return 0;
}

void app_main(void)
{
    ESP_ERROR_CHECK(ainekio_p4_board_init());
    ainekio_p4_board_identify();
    /* Do not erase an existing NVS partition on an initialization error. */
    ESP_ERROR_CHECK(nvs_flash_init());
    ESP_ERROR_CHECK(ainekio_p4_config_init());
    ESP_ERROR_CHECK(ainekio_p4_system_start());
    ESP_ERROR_CHECK(ainekio_p4_network_prepare());
    /* Optional asset media must never format an existing filesystem or stop
     * body startup when no asset partition has been installed. */
    const esp_err_t assets = ainekio_p4_assets_init();
    if (assets != ESP_OK) printf("assets unavailable: %s\n", esp_err_to_name(assets));
    ESP_ERROR_CHECK(ainekio_p4_controller_start());
    const esp_err_t media = ainekio_p4_controller_media_start();
    if (media != ESP_OK) printf("media initialization: %s\n", esp_err_to_name(media));
    const esp_err_t display = ainekio_p4_display_start();
    if (display != ESP_OK) printf("display initialization: %s\n", esp_err_to_name(display));
    /* Complete one-time NVS provisioning before enabling PWM. Never retry a
     * stalled mechanism automatically following a watchdog or brownout reset. */
    const esp_reset_reason_t reset = esp_reset_reason();
    if (!ainekio_p4_calibration().saved) {
        puts("No saved joint mapping; startup leaves outputs disabled.");
    } else if (reset == ESP_RST_POWERON || reset == ESP_RST_EXT || reset == ESP_RST_SW ||
        reset == ESP_RST_USB || reset == ESP_RST_JTAG) {
        if (ainekio_p4_home_command(1, NULL) != 0) puts("automatic home unavailable; outputs disabled");
    } else printf("automatic home inhibited after reset=%d; use home to retry\n", reset);
    ESP_ERROR_CHECK(ainekio_p4_network_start());
    esp_console_repl_t *repl = NULL;
    const esp_console_dev_uart_config_t uart = ESP_CONSOLE_DEV_UART_CONFIG_DEFAULT();
    esp_console_repl_config_t config = ESP_CONSOLE_REPL_CONFIG_DEFAULT();
    /* Keep the measured console stack budget for offline gait diagnostics. */
    config.task_stack_size = 12288;
    config.prompt = "ainekio-p4>";
    config.max_cmdline_length = 1024;
    ESP_ERROR_CHECK(esp_console_new_repl_uart(&uart, &config, &repl));
    ESP_ERROR_CHECK(esp_console_register_help_command());
    const esp_console_cmd_t identify = {.command="board", .help="Board and output status", .func=board_command};
    const esp_console_cmd_t stop = {.command="disable", .help="Latch direct emergency output disable", .func=disable_command};
    ESP_ERROR_CHECK(esp_console_cmd_register(&identify));
    ESP_ERROR_CHECK(esp_console_cmd_register(&stop));
    const esp_console_cmd_t network = {.command="net", .help="Network status; net ap/retry/key", .func=ainekio_p4_network_command};
    const esp_console_cmd_t configure = {.command="config", .help="Configure home, Wi-Fi or controller; commits then restarts", .func=ainekio_p4_config_command};
    ESP_ERROR_CHECK(esp_console_cmd_register(&network));
    ESP_ERROR_CHECK(esp_console_cmd_register(&configure));
    const esp_console_cmd_t controller = {.command="controller", .help="Selected controller session and readiness", .func=ainekio_p4_controller_command};
    const esp_console_cmd_t home = {.command="home", .help="Resume saved startup home after a stop", .func=ainekio_p4_home_command};
    ESP_ERROR_CHECK(esp_console_cmd_register(&controller));
    const esp_console_cmd_t system = {.command="system", .help="System status; profile/state/storage/restart", .func=ainekio_p4_system_command};
    ESP_ERROR_CHECK(esp_console_cmd_register(&system));
    const esp_console_cmd_t gait = {.command="gait", .help="Inspect installed geometric gait; no PWM output", .func=ainekio_p4_gait_command};
    ESP_ERROR_CHECK(esp_console_cmd_register(&gait));
    const esp_console_cmd_t face = {.command="face", .help="Display status; face list / NAME / auto", .func=ainekio_p4_display_command};
    ESP_ERROR_CHECK(esp_console_cmd_register(&face));
    ESP_ERROR_CHECK(esp_console_cmd_register(&home));
    ESP_ERROR_CHECK(esp_console_start_repl(repl));
}

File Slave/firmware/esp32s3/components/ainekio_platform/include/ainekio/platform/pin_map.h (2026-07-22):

#ifndef AINEKIO_PLATFORM_PIN_MAP_H
#define AINEKIO_PLATFORM_PIN_MAP_H

#include <stdbool.h>
#include <stdint.h>

#include "ainekio/protocol.h"
#include "sdkconfig.h"

#if !CONFIG_AINEKIO_PIN_MAP_B
#error "No reviewed Ainekio ESP32-S3 pin map is selected"
#endif

#define AINEKIO_BOARD_PROFILE_ID "freenove-esp32s3-cam-n16r8-map-b-remap"
#define AINEKIO_EXPECTED_FLASH_BYTES (16U * 1024U * 1024U)
#define AINEKIO_EXPECTED_PSRAM_BYTES (8U * 1024U * 1024U)

#define AINEKIO_PIN_BOOT 0
#define AINEKIO_PIN_BATTERY_ADC 3
#define AINEKIO_PIN_I2S_MIC_DIN 19
#define AINEKIO_PIN_I2S_AMP_DOUT 20
#define AINEKIO_PIN_I2S_BCLK 41
#define AINEKIO_PIN_I2S_WS 42
#define AINEKIO_PIN_UART_TX 43
#define AINEKIO_PIN_UART_RX 44

/*
 * GPIO0 is sampled by the ROM at reset, then becomes the OLED SDA line.
 * GPIO43 carries boot-time UART output, then becomes the OLED SCL line.
 */
#define AINEKIO_PIN_I2C_SDA AINEKIO_PIN_BOOT
#define AINEKIO_PIN_I2C_SCL AINEKIO_PIN_UART_TX

#define AINEKIO_PIN_SD_CMD 38
#define AINEKIO_PIN_SD_CLK 39
#define AINEKIO_PIN_SD_DAT0 40

#define AINEKIO_PIN_CAMERA_PWDN -1
#define AINEKIO_PIN_CAMERA_RESET -1
#define AINEKIO_PIN_CAMERA_XCLK 15
#define AINEKIO_PIN_CAMERA_SCCB_SDA 4
#define AINEKIO_PIN_CAMERA_SCCB_SCL 5
#define AINEKIO_PIN_CAMERA_D0 11
#define AINEKIO_PIN_CAMERA_D1 9
#define AINEKIO_PIN_CAMERA_D2 8
#define AINEKIO_PIN_CAMERA_D3 10
#define AINEKIO_PIN_CAMERA_D4 12
#define AINEKIO_PIN_CAMERA_D5 18
#define AINEKIO_PIN_CAMERA_D6 17
#define AINEKIO_PIN_CAMERA_D7 16
#define AINEKIO_PIN_CAMERA_VSYNC 6
#define AINEKIO_PIN_CAMERA_HREF 7
#define AINEKIO_PIN_CAMERA_PCLK 13

#define AINEKIO_PIN_SERVO_R1 1
#define AINEKIO_PIN_SERVO_R2 2
#define AINEKIO_PIN_SERVO_L1 14
#define AINEKIO_PIN_SERVO_L2 21
#define AINEKIO_PIN_SERVO_R4 47
#define AINEKIO_PIN_SERVO_R3 48
#define AINEKIO_PIN_SERVO_L3 45
#define AINEKIO_PIN_SERVO_L4 46

typedef struct {
    uint8_t joint_id;
    const char *label;
    int gpio;
    uint8_t mcpwm_group;
    uint8_t mcpwm_operator;
    uint8_t mcpwm_generator;
    bool positive_angle;
} ainekio_servo_pin_t;

extern const ainekio_servo_pin_t ainekio_servo_pins[AINEKIO_SERVO_COUNT];

bool ainekio_pin_is_reserved_for_sd(int gpio);
bool ainekio_pin_is_reserved_for_psram(int gpio);
bool ainekio_pin_map_valid(void);

#endif

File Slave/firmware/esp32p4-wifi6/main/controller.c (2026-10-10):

#include "controller.h"
#include "board.h"
#include "config.h"
#include "ainekio/v2_limits.h"
#include "network.h"
#include "gateway_selection.h"
#include "body.h"
#include "display.h"
#include "system.h"
#include "storage.h"
#include "ainekio/p4_media.h"
#include "ainekio/binary_codec.h"
#include "ainekio/admission.h"
#include "ainekio/control_encode.h"
#include "ainekio/v2_motion.h"
#include "ainekio/v2_walk.h"

#include <inttypes.h>
#include <stdatomic.h>
#include <stdio.h>
#include <stdlib.h>
#include <errno.h>
#include <string.h>
#include "cJSON.h"
#include "esp_crt_bundle.h"
#include "esp_app_desc.h"
#include "esp_log.h"
#include "esp_system.h"
#include "esp_wifi.h"
#include "esp_heap_caps.h"
#include "esp_timer.h"
#include "esp_websocket_client.h"
#include "freertos/FreeRTOS.h"
#include "freertos/queue.h"
#include "freertos/task.h"

typedef struct {
    uint64_t connection, output_generation, received_us;
    bool admitted_stop;
    ainekio_control_message_t message;
} request_t;
typedef struct {
    uint64_t connection;
    char *text;
} reply_t;
typedef struct {
    uint64_t connection;
    uint32_t sequence;
    char text[192];
} media_event_t;
typedef struct {
    uint64_t connection;
    uint8_t *bytes;
    size_t length;
    uint32_t done_sequence;
    bool wake_word;
    char metadata[192];
} packet_t;

static portMUX_TYPE admission_lock = portMUX_INITIALIZER_UNLOCKED;
static ainekio_admission_t admission;
static QueueHandle_t requests, replies;
static QueueHandle_t audio_packets, camera_packets, media_events;
/* Only this command's completion waits for its ACK/NAK to enter replies.
 * Media streaming and unrelated completions never wait for command execution. */
static atomic_uint pending_sequence;
static atomic_uint microphone_counter, microphone_tx_drops, camera_tx_drops;
static atomic_uint stopped_sequence;
static atomic_uchar camera_fps;
static atomic_bool initialized, reconnect, quiesced;
static atomic_int display_link_state, display_rejection;
/* One WebSocket instance at a time. The link task drains/stops the old client
 * before creating another; queued results can never cross into its successor. */
static uint64_t link_generation;
static char receive_text[4097];
static size_t receive_used, frame_received;
static uint8_t receive_opcode;
typedef struct {
    bool active, ready;
    uint32_t network_generation;
    esp_err_t result;
    size_t count;
    char endpoints[AINEKIO_DISCOVERY_MAX_RESULTS][AINEKIO_DISCOVERY_ENDPOINT_CAPACITY];
} gateway_discovery_t;
static portMUX_TYPE discovery_lock = portMUX_INITIALIZER_UNLOCKED;
static gateway_discovery_t discovery;

static void cancel_audio(uint64_t connection, ainekio_cancel_code_t code);
static void telemetry(uint64_t connection);
static bool current_connection(uint64_t connection);

static uint64_t now_us(void) { return esp_timer_get_time(); }
static void enter(void) { portENTER_CRITICAL(&admission_lock); }
static void leave(void) { portEXIT_CRITICAL(&admission_lock); }

ainekio_connection_gateway_t ainekio_p4_controller_display_status(void)
{
    enter();
    const bool authenticated = admission.authenticated, connected = admission.connected;
    leave();
    if (authenticated) return AINEKIO_SCREEN_GATEWAY_ONLINE;
    const int rejection = atomic_load(&display_rejection);
    if (rejection) return rejection;
    if (connected) return AINEKIO_SCREEN_GATEWAY_HANDSHAKE;
    return atomic_load(&display_link_state);
}

static void fail_link(void)
{
    atomic_store(&display_link_state, AINEKIO_SCREEN_GATEWAY_UNAVAILABLE);
    enter();
    const bool had_controller = admission.authenticated;
    if (admission.connected) ainekio_admission_close(&admission, admission.generation);
    if (had_controller) ainekio_pca_emergency_disable(ainekio_p4_output(), AINEKIO_PCA_FAULT_EMERGENCY);
    leave();
    atomic_store(&reconnect, true);
}

/* Caller holds admission_lock. Enforce the physical timeout before a late
 * frame can refresh admission, without tearing down the telemetry bridge. */
static bool control_current(uint64_t connection, uint64_t now)
{
    if (ainekio_admission_check_stale(&admission, now))
        ainekio_pca_emergency_disable(ainekio_p4_output(), AINEKIO_PCA_FAULT_EMERGENCY);
    return ainekio_admission_control(&admission, connection, now);
}

void ainekio_p4_controller_quiesce(void)
{
    atomic_store(&quiesced, true);
    enter();
    ainekio_admission_close(&admission, admission.generation);
    ainekio_pca_emergency_disable(ainekio_p4_output(), AINEKIO_PCA_FAULT_EMERGENCY);
    leave();
    atomic_store(&reconnect, true);
}

static void reply(uint64_t connection, const char *text)
{
    reply_t response = {.connection=connection, .text=strdup(text)};
    if (!response.text) { fail_link(); return; }
    if (xQueueSend(replies, &response, 0) != pdTRUE) {
        free(response.text);
        fail_link();
    }
}

static void nak(uint64_t connection, const ainekio_control_message_t *m, ainekio_reject_reason_t reason)
{
    static const ainekio_nak_code_t codes[] = {
        AINEKIO_NAK_UNKNOWN, AINEKIO_NAK_STALE, AINEKIO_NAK_MODE, AINEKIO_NAK_UNSAFE,
        AINEKIO_NAK_LIMIT, AINEKIO_NAK_UNKNOWN, AINEKIO_NAK_BUSY, AINEKIO_NAK_PROFILE,
        AINEKIO_NAK_ASSET_MISSING, AINEKIO_NAK_MALFORMED,
    };
    char text[180];
    const char *detail = reason == AINEKIO_REJECT_LIMIT ?
        "Command parameters are outside their supported range" :
        reason == AINEKIO_REJECT_BUSY ? "Body is busy, asleep, or its outputs are unavailable" : NULL;
    ainekio_encode_nak(m->has_sequence, m->sequence, codes[reason], detail, text, sizeof(text));
    reply(connection, text);
}
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

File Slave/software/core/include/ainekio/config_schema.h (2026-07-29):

#ifndef AINEKIO_CONFIG_SCHEMA_H
#define AINEKIO_CONFIG_SCHEMA_H

#include <stdint.h>

#define AINEKIO_NVS_SCHEMA_VERSION UINT32_C(1)

/*
 * The inactive slot is staging. After validation, one metadata commit bumps
 * schema_ver and switches active_slot; an interrupted stage leaves the old slot
 * selected.
 */
#define AINEKIO_NVS_NAMESPACE_META "ainekio_meta"
#define AINEKIO_NVS_NAMESPACE_CONFIG_A "config_a"
#define AINEKIO_NVS_NAMESPACE_CONFIG_B "config_b"
#define AINEKIO_NVS_NAMESPACE_DEVICE "device_setup"
#define AINEKIO_NVS_NAMESPACE_CALIBRATION "robot_cal"
#define AINEKIO_NVS_NAMESPACE_POSES "robot_poses"
#define AINEKIO_NVS_NAMESPACE_PREFERENCES "robot_prefs"

#define AINEKIO_NVS_KEY_SCHEMA_VERSION "schema_ver"
#define AINEKIO_NVS_KEY_ACTIVE_SLOT "active_slot"
#define AINEKIO_NVS_KEY_SETUP_KEY "setup_key"
#define AINEKIO_NVS_KEY_LOCAL_GATEWAY "last_gateway"
#define AINEKIO_SETUP_KEY_CHARS 8U

#define AINEKIO_NVS_KEY_GENERATION "generation"
#define AINEKIO_NVS_KEY_COMPLETE "complete"
#define AINEKIO_NVS_KEY_WIFI_SSID "wifi_ssid"
#define AINEKIO_NVS_KEY_WIFI_PSK "wifi_psk"
#define AINEKIO_NVS_KEY_TRANSPORT_MODE "transport"
#define AINEKIO_NVS_KEY_ENDPOINT_URL "endpoint_url"
#define AINEKIO_NVS_KEY_ROBOT_ID "robot_id"
#define AINEKIO_NVS_KEY_ROBOT_TOKEN "robot_token"

#define AINEKIO_TRANSPORT_LOCAL "local"
#define AINEKIO_TRANSPORT_REMOTE "remote"

#define AINEKIO_NVS_KEY_SERVO_CALIBRATION "servo_cal_v1"
#define AINEKIO_NVS_KEY_NAMED_POSES "named_pose_v1"
#define AINEKIO_NVS_KEY_DEFAULT_PROFILE "profile"
#define AINEKIO_NVS_KEY_ADC_FACTOR "adc_factor"
#define AINEKIO_NVS_KEY_WAKE_ENABLED "wake_enabled"
#define AINEKIO_NVS_KEY_WAKE_MODEL "wake_model"

typedef enum {
    AINEKIO_CONFIG_SLOT_NONE = 0,
    AINEKIO_CONFIG_SLOT_A = 1,
    AINEKIO_CONFIG_SLOT_B = 2,
} ainekio_config_slot_t;

#endif

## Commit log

2026-07-04 Add Ainekio static site
    [Example-Configuration.txt]
2026-07-04 Revert "Add Ainekio static site"
    This reverts commit 90f71ac78c179460eb3116613e3b851571040bb3.
    [Example-Configuration.txt]
2026-07-08 Add Sesame simulator runtime
    [bottom_cover.stl, femur_joint_l1.stl, femur_joint_l2.stl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]
2026-07-14 Establish master slave and emulator architecture
    [L1.blend, L1V1.stl, L2.blend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]
2026-07-14 Complete Ainekio software stack
    [Frame1.blend, FrameV1.stl, R1V1.stl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]
2026-07-18 Complete robot audio, motion, and hardware updates
    [L1V3.blend, L1V3.stl, L4V2.blend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]
2026-07-22 Harden ESP32-S3 runtime and update hardware assets
    [Board-hold-back.stl, Board-hold1.stl, Board-hold2.stl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]
2026-07-23 Add Cloudflare Robot Relay Deployment Documentation and Token Generation Script
    - Created a comprehensive deployment document for the Cloudflare Robot Relay, detailing the architecture, security boundaries, reliability considerations, and acceptance gates.
    - Document outlines the purpose, confirmed starting state, and implementation phases for the relay system.
    - Added an audit trail to track the deployment process and decisions made by the owner regarding the use of Cloudflare as a transport.
    - Introduced a token generation script to facilitate the creation of necessary tokens for the Ainekio robot and environment adapter, ensuring secure communication.
2026-07-23 Harden physical runtime and camera pipeline
    [Frame4.blend, Frame5.blend, oled-box1.stl]
2026-07-29 Expand robot control, speech, and hardware assets
    [Bottom-Housing1.stl, Frame5.blend, Frame6.blend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]
2026-08-03 Expand robot runtime controls and hardware assets
    [Frame7.blend, Frame7.stl, L4V9.stl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]
2026-08-04 Expand robot motion, audio, and firmware behavior
    [R2VI5.blend, R2VI5.stl, partitions.csv]
2026-09-06 Expand semantic motions and hardware assets
    [Frame8.blend, Frame8.stl, R1VI5.blend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]
2026-09-21 Add V2 firmware, motion library, and model-specific hardware assets
    [12degrees1.blend, 12degrees1body-wip.blend, 12degrees1body.blend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]
2026-09-23 Update P4 firmware, body controls, and V2 motion assets
    Add P4 body execution, calibration, provisioning, media, storage, and power services. Consolidate shared protocol encoding and wake support, update gateway controls and tests, and refresh V2 motion sources, validation, and hardware assets.
    Keep oversized local Blender working copies out of this publication.
    Validation: 28 native tests passed; 94 focused Python tests passed with 3 skips; dashboard motion race checks passed.
    [Ainekio-Neck-Reference-Refined-Live-Recovery1-REFINED RL Part_009 - 24mm recessed horn crank - plain joint bore.stl, ainekio-variable-gait-REFINED RL Part_026 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]
2026-09-24 Update V2 motions and body controls; keep Blender scenes local
    Add continuous Crab controls and revised gesture assets, fix P4 command advertisement sizing, and record the verified firmware deployment. Preserve STL exports while ignoring Blender scenes, backups and oversized local gait renders.
    Validation: 29 native tests, 72 gateway/protocol tests, dashboard motion tests, compact geometry comparison, and ESP32-P4 build/flash verification passed.
    [12degrees1.blend, 12degrees1body-wip.blend, 12degrees1body.blend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]
2026-09-26 Update gait geometry, motion speed controls and carrier STL exports
    Publish current P4, protocol and Body Control changes, regenerated gait assets, validation notes and two carrier STL exports. Blender scenes remain local and ignored.
    Publication checks: 27 selected native tests and dashboard motion tests passed. Python checks passed 69 of 71 tests; two coverage checks report missing fixtures for motion_speed and motion_speed_status. Preserve the owner snapshot without unrelated fixes.
    [ainekio-variable-gait-Recovery-REFINED RL Part_023 - 4.9mm outside-horn carrier - plain joint bore.stl, ainekio-variable-gait-Recovery-REFINED RR Part_023 - 4.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]
2026-09-30 Update Body Control, P4 settings, motion assets and integration docs
    Persist dashboard authentication and manage P4 network profiles and pairing
    through Body Control. Include movement lifecycle and camera perception updates.
    Refresh V2 motion and calibration assets, publish hardware reference models
    and STL exports, add the portable IMU estimation component, and document ROS 2
    setup and integration boundaries.
    [GY_LSM6DS3_reference_no_headers.step, GY_LSM6DS3_reference_with_headers.step, Right-Center Mount.001.stl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]
2026-10-01 Add camera recognition, camera profiles and continuous steering
    [ainekio-variable-gait-Recovery-Carapace - Right Side Protector.stl, ainekio-variable-gait-Recovery-REFINED FL Part_003 - original mount - separate rectangular 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]
2026-10-01 Fix steering negotiation and authenticated remote recognition
    Negotiate walk_steering_v1 separately from walk_controls_v2, advertise only
    supported controls, and reject unsupported or malformed steering before dispatch.
    Run alias normalization cannot discard steering fields. Preserve existing
    commands, emergency stop, execution limits and action/update receipt semantics.
    Extend the existing recognition client to explicitly configured remote HTTPS
    services with API-key authentication, certificate/hostname verification,
    bounded responses and timeouts. Report correlated failures through the existing
    observation path without introducing another runtime or execution authority.
    Include the exist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
    [controller.c]
2026-10-01 Add front and rear structural crossbar STL exports
    [ainekio-variable-gait-Recovery-STRUCTURAL Center support crossbar - Front.stl, ainekio-variable-gait-Recovery-STRUCTURAL Center support crossbar - Rear.stl]
2026-10-02 Fix portable Body Control pairing and P4 gateway switching
    Share saved robot pairing and dashboard credentials across hosts, negotiate gateway switching, and preserve one active P4 session without command replay.
    Validation: 53 focused tests, 9 native regressions and 23 browser checks passed. Aggregate: 29/31. Existing failures and SDK/hardware blockers are recorded in docs/BODY_CONTROL_INTEGRATION.md.
    [controller.c]
2026-10-02 Add configurable joint speed limits, motion diagnostics and body CAD exports
    [ainekio-variable-gait-Recovery-TESTS Body - Left HDMI access cover.stl, ainekio-variable-gait-Recovery-TESTS Body - Rear End Panel - Q6A Ports.stl, ainekio-var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]
2026-10-03 Update robot gait calibration, gateway networking and CAD exports
    [ainekio-variable-gait-Recovery-REFINED FL Part_027 - 24mm pickup short collar - plain joint bore.stl, ainekio-variable-gait-Recovery-REFINED FR Part_027 - 24mm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]
2026-10-04 Refine calibrated gaits and gestures and add hardware references
    [ainekio-variable-gait-Recovery-Radxa_Dragon_Q6A_Bottom_Slot.002.stl, ainekio-variable-gait-Recovery-Radxa_Dragon_Q6A_Top_Slots.stl, ainekio-variable-gait-Recov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]
2026-10-07 feat(robot): add P4 faces, media controls and updated linkage assets
    [ainekio-variable-gait-Recovery-MASK Recessed LCD bezel.stl, ainekio-variable-gait-Recovery-MOUNT Wireless LCD carrier spacer 1.stl, ainekio-variable-gait-Recov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]
2026-10-07 fix(gateway): confirm owned motion termination and add carrier export
    [ainekio-variable-gait-Recovery-REFINED FL Part_023 - 35mm carrier - 4.9mm outside-horn - plain joint bore.stl]
2026-10-08 chore(hardware): add LCD carrier braces and speaker housing exports
    [ainekio-variable-gait-Recovery-STRUCTURAL Front panel brace - Left.stl, ainekio-variable-gait-Recovery-STRUCTURAL Front panel brace - Right.stl, ainekio-variab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]
2026-10-10 feat(robot): update perception, face feedback, firmware and hardware exports
    [ainekio-variable-gait-Recovery-CHIN Compact camera retainer.stl, ainekio-variable-gait-Recovery-MONITOR Anker lower saddle - left.stl, ainekio-variable-gait-Re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]
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2026-10-19 fix(robot): smooth servo feedback and track leveling demand
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2026-10-22 feat(robot): integrate motion feedback, adaptive camera and gait learning
    Publish Body Control and firmware updates for feedback-aware motion, connection handling, gait learning and visualization. Include revised face rendering and galleries, printable robot parts, and the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
2026-10-24 fix(gateway): preserve relay startup and document reboot workflow
2026-10-25 feat(robot): add editable compact motion training library
    Add paginated and sortable training-example editing, direct playback, and compact exports. Keep only current refined targets and prevent discarded examples from returning through imports.
    Include compact inference and continuous execution changes, servo feedback recovery, and dashboard audio and hotspot fixes.
    Validate library retention and dashboard routes, motion compilation, UI behavior, launcher and hotspot tests, and native firmware tests. Prepare the cleaned 889-example training dataset without launching training or changing the deployed model.
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
